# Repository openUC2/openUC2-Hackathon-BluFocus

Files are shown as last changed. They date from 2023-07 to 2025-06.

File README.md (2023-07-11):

# Hackathon: openOCT - Full-field Incoherent Interferemeter for better optical sectioning with remote control capabilities

Welcome to the openOCT Hackathon! In this hackathon, we will be addressing the crucial need for an open-source optical coherence tomography system that can help students learning more about setting up a low-coherence interferemoter. To keep the budget low, we aim for a full-field time domain OCT using an SLD (super luminescent diode) - alternatively one could also try an LED to lower the costs even more


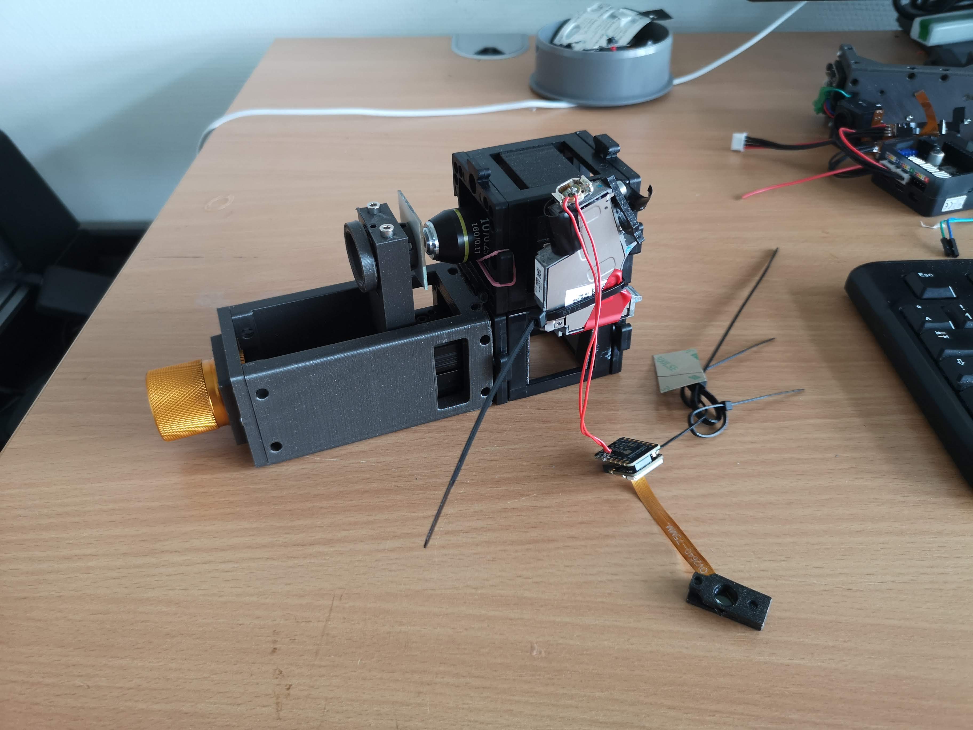
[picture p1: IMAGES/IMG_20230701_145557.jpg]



## Motivation

Autofocus is a critical feature in microscopy as it helps to keep the sample in focus, resulting in high-quality imaging. Currently, there are software-based autofocus systems that maximize contrast based on the z-position of the sample or objective. However, hardware-based autofocus systems provide alternative solutions. These systems typically utilize a laser coupled into the detection path, reflecting off the sample (e.g., coverslip), and reaching a detector (e.g., quadrant diode, camera) via a beamsplitter. As the sample moves along the optical axis, the detected beam on the detector changes as a function of *z*, which can be processed using various techniques or electric circuits.

While some major microscope manufacturers offer hardware-based autofocus systems, they tend to be expensive. Software-based systems, on the other hand, are slow and lack real-time functionality. Although neural network-based systems show promise, they are not yet stable enough. Thus, there is a clear need for an open-source hardware-based autofocus system that is affordable, precise, and accessible to anyone.

For further reading on the topic, we recommend the review article "Advances in Hardware Autofocus Systems for Microscopy" available at: [Link to Article](https://arxiv.org/pdf/2006.08610.pdf)

## Goal

The primary objective of this hackathon is to build an affordable hardware module for autofocus using readily available components, namely the optical pickup unit (OPU) from a PS3 Bluray drive and the SEEED XIAO ESP32-S3 Camera. The PS3 OPU employs an astigmatism-based autofocus technique, which maintains a constant distance between the disk and the detection lens. To replicate this functionality, we will replace the quadrant diode with a camera and utilize image processing algorithms, either on the ESP32 microcontroller or in Python, to compute the astigmatism as a function of the focus along the z-axis.

Ultimately, the goal is to create a hardware module capable of continuously tracking the focus and providing a signal to a motor, ensuring that the focus remains constant during microscopy experiments.

## Background

The use of optical pickup units (OPUs) from Bluray/HD-DVD players has been extensively explored in various applications, including force measurements, atomic force microscopy, nanoprinting, and laser scanning microscopy. These OPUs are highly integrated photonic devices with immense potential. If you're interested in delving deeper into OPU hacking, there are informative forum discussions available at: [Link to Forum](https://forum.hackteria.org/t/laser-optical-pickup-unit-hacking/771/24)

To gain a comprehensive understanding, we recommend watching this enlightening video: [Link to Video](https://www.youtube.com/watch?v=5bqujaldaCQ&ab_channel=EdwinHwu)

For a concise summary of OPU hacking, you can refer to this document: [Link to Summary](https://drive.google.com/file/d/1NFffRgITiLQYtSXz-uS6AOUKJFVFwoh7/view)

OPUs are widely available in large quantities as discarded electronic components, making them an ideal resource for hacking and repurposing.

The SEEED XIAO ESP32-S3 Camera, integrated with the ESP32 microcontroller, provides a convenient solution for streaming images over USB or Wi-Fi. Also, the microcontroller has enough power to do basic image processing such as gaussian bluring, min/max estimation, etc. Enough to evtl. do the focus computation on the device before transmitting the information to e.g. a computer.

## Current State: Building the Prototype

At present, we have a functional prototype that combines the SEEED XIAO ESP32-S3 camera (OV2640 chip) with the PS3 OPU (KES400A) for the autofocus system. During the prototyping phase, we utilize a red diode (650nm) instead of UV (405nm) or IR (850nm) to facilitate beam visibility. However, using NIR (near-infrared) diodes would be more suitable for fluorescence excitation and maintaining invisibility.

To modify the OPU, we remove the focusing lens and quadrant diode. In place of the quadrant diode, we position the camera without its lens to detect the astigmatism. This assembly is attached to a microscope objective lens, and a simple coverslip serves as a beamsplitter. The beam from the OPU to the objective lens' back focal plane (BFP) is collimated. Ideally, the camera should be confocal with the sample plane. The entire assembly takes the form of a cube, with the mirror adjustable to ensure it hits the BFP in the center and remains parallel to the optical axis.

To protect the camera (or flatband cable) from immediate damage, we use a camera with a long cable.

The simplest prototype involves replacing the diode with the camera and substituting the read-out lens with the objective lens.

### 3D printed assembly

All design files are available in the [INVENTOR](./INVENTOR) folder

All 3D printing files are available in the [STL](./STL)  folder

Setup from bottom view: 3  (ball-loaded) set screws in combination with 2 pulling springs allow the beamsplitter (18x18mm^2 coverslip) to be adjusted w.r.t. the BFP of the objective lens
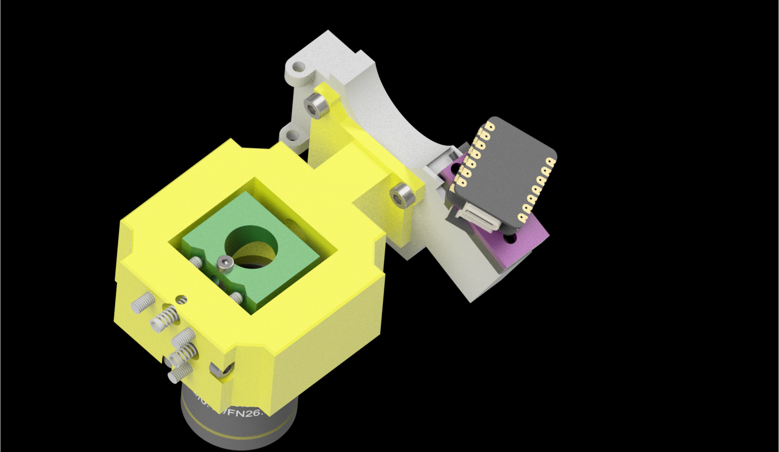
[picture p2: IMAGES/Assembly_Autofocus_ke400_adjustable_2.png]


The XIAO camera is mounted in place of the quadrant diode (A holding mechanism is missing)
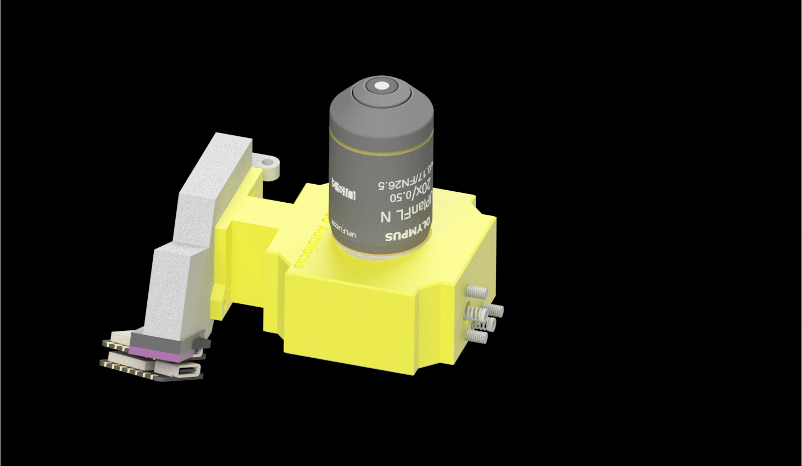
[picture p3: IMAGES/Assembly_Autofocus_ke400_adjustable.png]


The camera comes under an angle since the cylindrical lens is not perpendicular to the pixels otherwise:


### Setting up and Adapting

To disassemble the OPU, you can remove the metal plate at the back and the detection lens using Philips screwdrivers.

The back of the OPU features a complex and precisely adjusted "confocal" microscope:

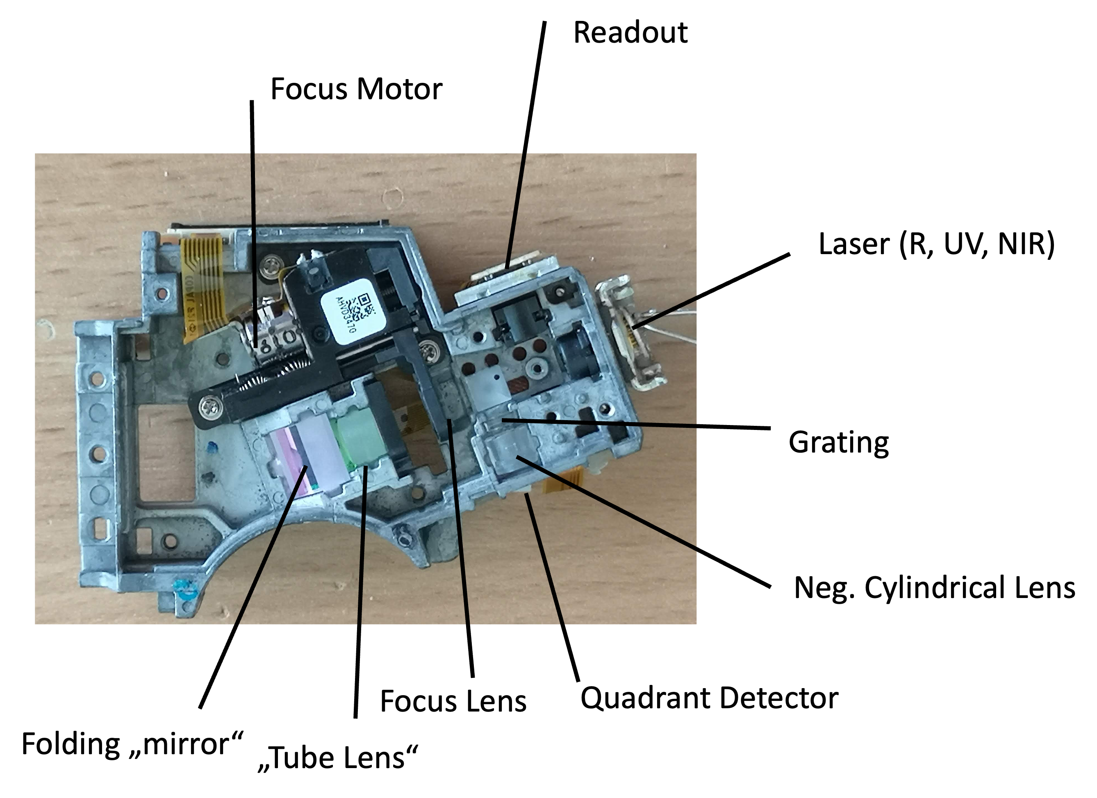
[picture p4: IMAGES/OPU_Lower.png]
OPU Lower

*Bottom View*

To attach this unit to a 3D printed assembly, we will enlarge the holes where the lens used to be, making them M3-sized, and then incorporate the assembly into a UC2 insert:

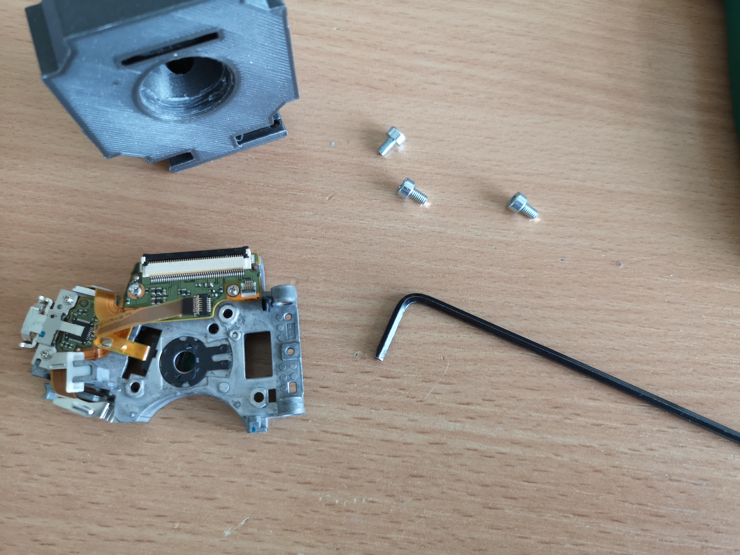
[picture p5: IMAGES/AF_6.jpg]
3D Printed Assembly


The Xiao camera module can be adapted using another 3D printed mechanism (customizable to your needs). It's worth noting that the astigmatism is not parallel to the case of the OPU, so it may be necessary to adjust the angle by rotating the camera. Additionally, the focus may be slightly closer than the plastic cap (black) of the camera module allows.

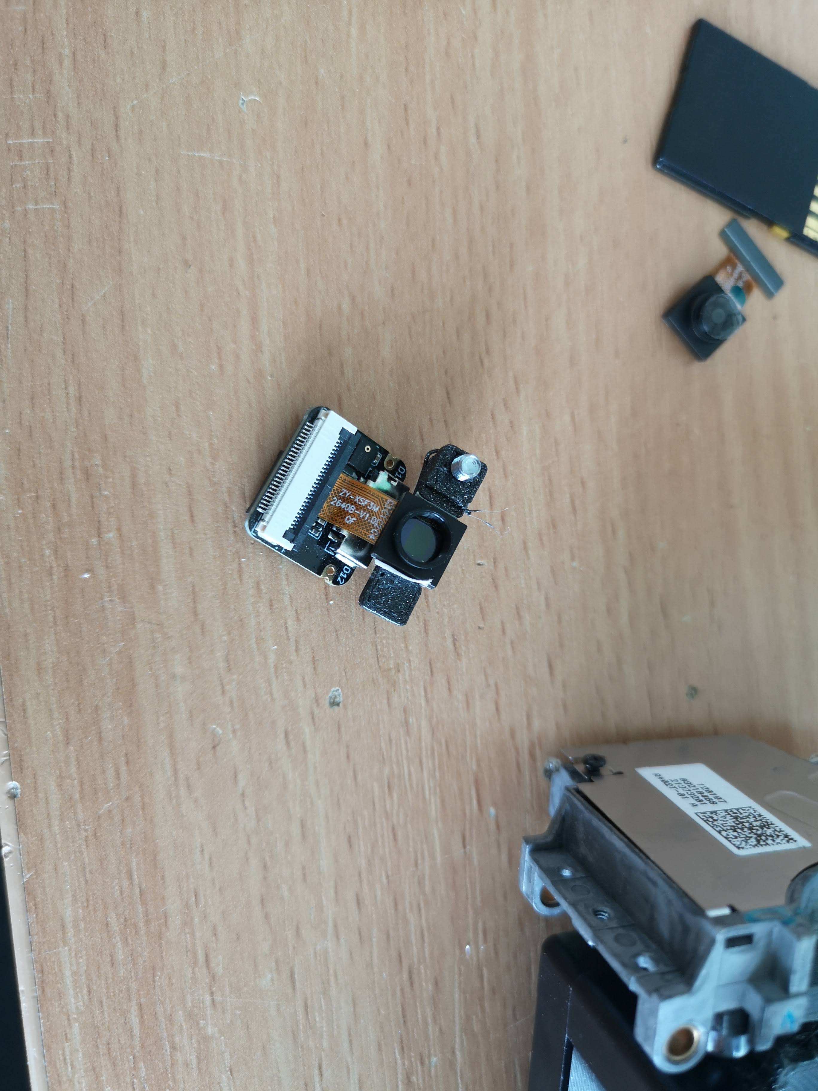
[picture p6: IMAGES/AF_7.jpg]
Xiao Camera Module


We create an initial prototype as follows:

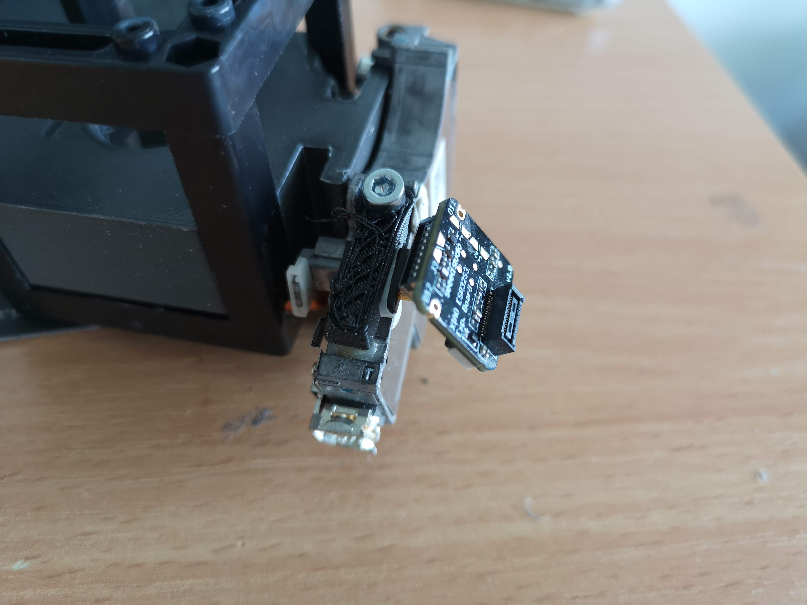
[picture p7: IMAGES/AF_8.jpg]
Prototype


It is advisable to mount the XIAO camera securely to prevent damage to the flatband cable:

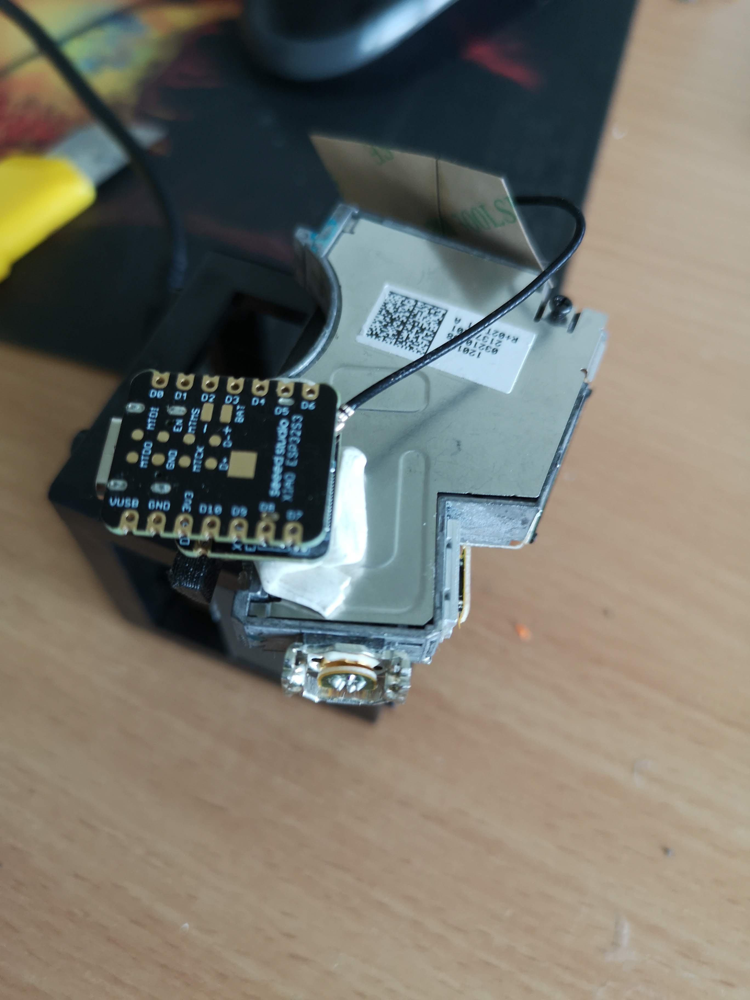
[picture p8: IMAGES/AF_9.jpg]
Secure Mounting


The laser diode can be directly powered by the 3V3 supply voltage or controlled using a transistor for on/off switching in the code.

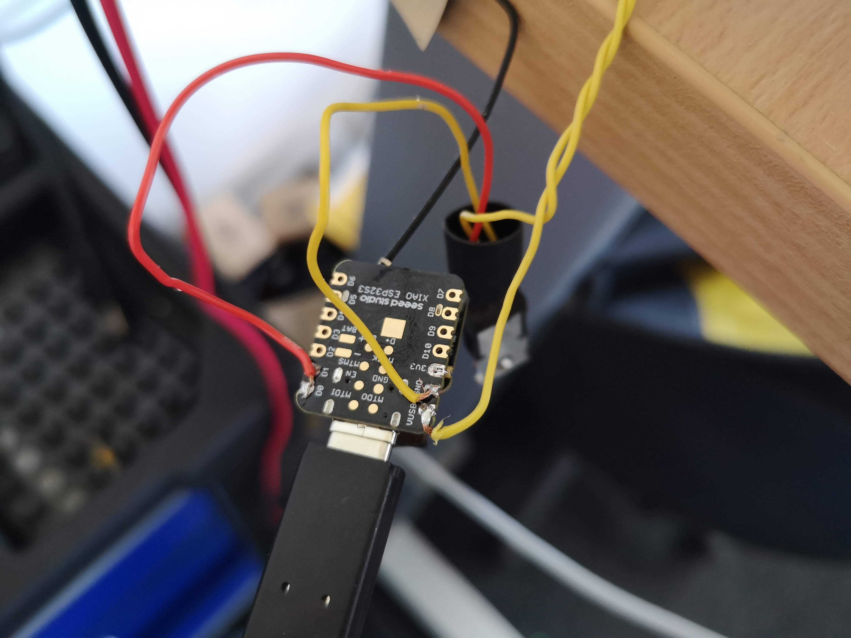
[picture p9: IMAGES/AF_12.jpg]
Laser Diode Setup


Fully assembled



### Optical Setup

The optical setup for the autofocus system involves several components and configurations. Here is an overview of the setup:

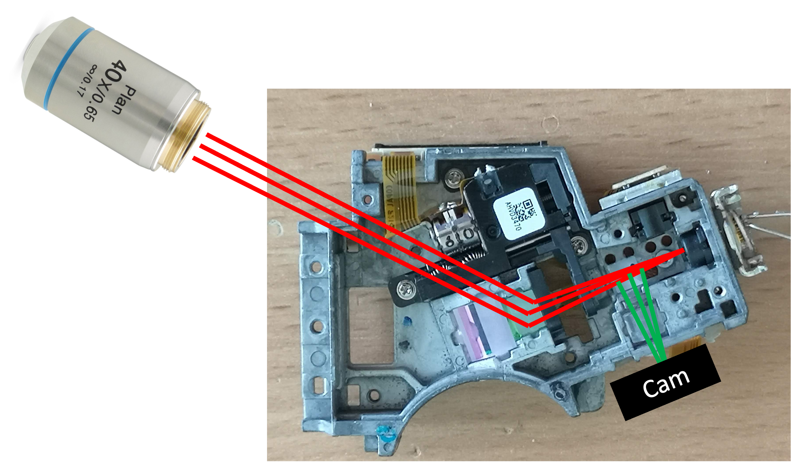
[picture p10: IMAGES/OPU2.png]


- Laser Collimation: The laser beam is roughly collimated using a lens that also features a grating. The purpose of the grating is yet to be determined.
- Spatial Light Modulator (SLM): The laser beam passes through a tiny SLM, which shapes the beam according to specific requirements.
- Polarizing Beam Splitters: The shaped beam is directed through two polarizing beam splitters before it is steered towards the objective lens.
- Polarization Rotation: The reflected light from the sample undergoes polarization rotation using a quarter-wave plate.
- Detection: The polarizing beam splitter reflects the light towards the detector. Between the beamsplitter and the detector, a small grating is positioned along with a negative cylindrical lens.
- Grating and Negative Cylindrical Lens: The combination of the grating and negative cylindrical lens plays a crucial role in the autofocus system:
  - A collimated beam results in a cross or the best-focused image on the detector.
  - An out-of-focus beam leads to a line structure along the x or y axis, depending on whether it is positively or negatively out of focus.
  - Typically, a quadrant detector is used to measure the differences between the sums of intensities (A-B)+(C-D).
  - The resulting S-curve can be used for absolute or relative focus tracking in a linear regime.
  - The S-curve switches signs at the outer regions because the astigmatism rotates as a function of atan2.

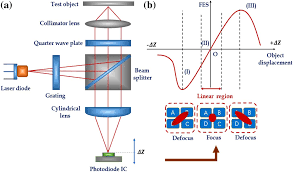
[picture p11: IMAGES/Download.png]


The practical implementation of this setup may look like the following animation:

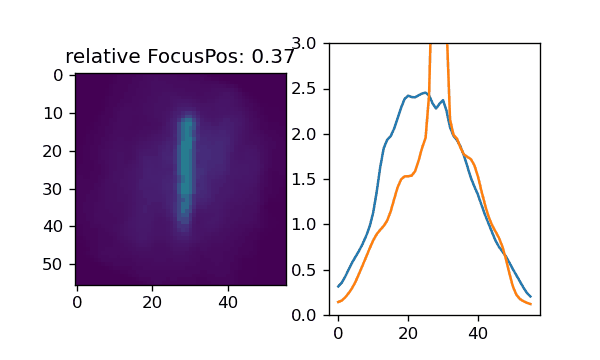
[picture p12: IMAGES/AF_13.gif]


The combination of these optical elements allows for precise detection and tracking of focus in the autofocus system.

### test Setup

Optical Setup Animation

### Code

The general code is divided into two pieces:
- cpp code that can be used in the aRduino IDE or better Platform.io in Visual studio code that reads out the camera, sets up expsoure and gain and converts the data to a byte stream to send it out via Serial
- python code to send data (E.g. request frame, setup camera parameter), receive the data and converts it to numpy arrays

The code is copied from our matchboxscope repository:
https://github.com/Matchboxscope/matchboxscope-simplecamera/tree/autofocus

#### ESP32

```cpp
#include "esp_camera.h"
#include <base64.h>

#define BAUD_RATE 2000000

#define PWDN_GPIO_NUM -1
#define RESET_GPIO_NUM -1
#define XCLK_GPIO_NUM 10
#define SIOD_GPIO_NUM 40
#define SIOC_GPIO_NUM 39

#define Y9_GPIO_NUM 48
#define Y8_GPIO_NUM 11
#define Y7_GPIO_NUM 12
#define Y6_GPIO_NUM 14
#define Y5_GPIO_NUM 16
#define Y4_GPIO_NUM 18
#define Y3_GPIO_NUM 17
#define Y2_GPIO_NUM 15
#define VSYNC_GPIO_NUM 38
#define HREF_GPIO_NUM 47
#define PCLK_GPIO_NUM 13

#define LED_GPIO_NUM 21

void grabImage();
void cameraInit();

void setup()
{
  Serial.begin(BAUD_RATE);
  Serial.setTimeout(20);
  cameraInit();
}

int Nx = 320;
int Ny = 240;
int Nroi = 50;
int x = 320 / 2;
int y = 240 / 2;
bool isStreaming = true;

/* setting expsorue time: t1000
setting gain: g1
getting frame: \n
restarting: r0 */
void loop()
{
  // Check for incoming serial commands
  if (Serial.available() > 0)
  {
    String command = Serial.readString(); // Read the command until a newline character is received
    if (command.length() > 1 && command.charAt(0) == 't')
    {
      // exposure time
      int value = command.substring(1).toInt(); // Extract the numeric part of the command and convert it to an integer
      // Use the value as needed
      // Apply manual settings for the camera
      sensor_t *s = esp_camera_sensor_get();
      s->set_gain_ctrl(s, 0);     // auto gain off (1 or 0)
      s->set_exposure_ctrl(s, 0); // auto exposure off (1 or 0)
      s->set_aec_value(s, value); // set exposure manually (0-1200)
    }
    else if (command.length() > 1 && command.charAt(0) == 'g')
    {
      // gain
      int value = command.substring(1).toInt(); // Extract the numeric part of the command and convert it to an integer

      // Apply manual settings for the camera
      sensor_t *s = esp_camera_sensor_get();
      s->set_gain_ctrl(s, 0);     // auto gain off (1 or 0)
      s->set_exposure_ctrl(s, 0); // auto exposure off (1 or 0)
      s->set_agc_gain(s, value);  // set gain manually (0 - 30)
    }
    else if (command.length() > 1 && command.charAt(0) == 'r')
    {
      // restart
      ESP.restart();
    }
    else
    {
      // capture image and return
      grabImage();
    }

    // flush serial
    while (Serial.available() > 0)
    {
      char c = Serial.read();
    }
  }
}

void cameraInit()
{

  camera_config_t config;
  config.ledc_channel = LEDC_CHANNEL_0;
  config.ledc_timer = LEDC_TIMER_0;
  config.pin_d0 = Y2_GPIO_NUM;
  config.pin_d1 = Y3_GPIO_NUM;
  config.pin_d2 = Y4_GPIO_NUM;
  config.pin_d3 = Y5_GPIO_NUM;
  config.pin_d4 = Y6_GPIO_NUM;
  config.pin_d5 = Y7_GPIO_NUM;
  config.pin_d6 = Y8_GPIO_NUM;
  config.pin_d7 = Y9_GPIO_NUM;
  config.pin_xclk = XCLK_GPIO_NUM;
  config.pin_pclk = PCLK_GPIO_NUM;
  config.pin_vsync = VSYNC_GPIO_NUM;
  config.pin_href = HREF_GPIO_NUM;
  config.pin_sscb_sda = SIOD_GPIO_NUM;
  config.pin_sscb_scl = SIOC_GPIO_NUM;
  config.pin_pwdn = PWDN_GPIO_NUM;
  config.pin_reset = RESET_GPIO_NUM;
  config.xclk_freq_hz = 20000000;
  // config.frame_size = FRAMESIZE_QVGA;
  // config.pixel_format = PIXFORMAT_JPEG; // for streaming
  // config.pixel_format = PIXFORMAT_RGB565; // for face detection/recognition
  config.grab_mode = CAMERA_GRAB_WHEN_EMPTY;
  config.fb_location = CAMERA_FB_IN_PSRAM;
  config.jpeg_quality = 12;

  config.pixel_format = PIXFORMAT_JPEG;
  config.frame_size = FRAMESIZE_QVGA; // for streaming}

  config.fb_count = 1;

  esp_err_t err = esp_camera_init(&config);
  if (err != ESP_OK)
  {
    return;
  }

  sensor_t *s = esp_camera_sensor_get();
  s->set_hmirror(s, 1);
  s->set_vflip(s, 1);

  // enable manual camera settings
  s->set_gain_ctrl(s, 0);     // auto gain off (1 or 0)
  s->set_exposure_ctrl(s, 0); // auto exposure off (1 or 0)
  s->set_aec_value(s, 100);   // set exposure manually (0-1200)
  s->set_agc_gain(s, 0);      // set gain manually (0 - 30)
}
void grabImage()
{

  camera_fb_t *fb = esp_camera_fb_get();

  if (!fb || fb->format != PIXFORMAT_JPEG)
  {
    Serial.println("Failed to capture image");
    ESP32.restart();
  }
  else
  {
    delay(40);

    String encoded = base64::encode(fb->buf, fb->len);
    Serial.write(encoded.c_str(), encoded.length());
    Serial.println();
  }

  esp_camera_fb_return(fb);
}
```

#### PYTHON

```py
import time
from threading import Thread
import numpy as np
import serial.tools.list_ports
import base64
from PIL import Image
import io

class CameraESP32CamSerial:
    def __init__(self):
        super().__init__()
        self.__logger = initLogger(self, tryInheritParent=True)

        # many to be purged
        self.model = "ESP32Camera"
        self.shape = (0, 0)

        self.isConnected = False

        # camera parameters
        self.framesize = 100
        self.exposure_time = 0
        self.analog_gain = 0

        self.SensorWidth = 320
        self.SensorHeight = 240

        self.manufacturer = 'Espressif'

        self.frame = np.ones((self.SensorHeight,self.SensorWidth))
        self.isRunning = False

        # string to send data to camera
        self.newCommand = ""
        self.exposureTime = -1
        self.gain = -1

        self.serialdevice = self.connect_to_usb_device()

    def connect_to_usb_device(self):
        ports = serial.tools.list_ports.comports()
        for port in ports:
            if port.manufacturer == self.manufacturer or port.manufacturer=="Microsoft":
                try:
                    ser = serial.Serial(port.device, baudrate=2000000, timeout=1)
                    print(f"Connected to device: {port.description}")
                    return ser
                except serial.SerialException:
                    print(f"Failed to connect to device: {port.description}")
        print("No matching USB device found.")
        return None

    def put_frame(self, frame):
        self.frame = frame
        return frame

    def start_live(self):
        self.isRunning = True
        self.mThread = Thread(target=self.startStreamingThread)
        self.mThread.start()

    def stop_live(self):
        self.isRunning = False
        self.mThread.join()
        try:self.serialdevice.close()
        except:pass

    def suspend_live(self):
        self.isRunning = False

    def prepare_live(self):
        pass

    def close(self):
        try:self.serialdevice.close()
        except:pass

    def setPropertyValue(self, property_name, property_value):
        # Check if the property exists.
        if property_name == "gain":
            self.set_analog_gain(property_value)
        elif property_name == "exposure":
            self.set_exposure_time(property_value)
        else:
            self.__logger.warning(f'Property {property_name} does not exist')
            return False
        return property_value

    def getPropertyValue(self, property_name):
        # Check if the property exists.
        if property_name == "gain":
            property_value = self.gain
        elif property_name == "exposure":
            property_value = self.exposureTime
        else:
            self.__logger.warning(f'Property {property_name} does not exist')
            return False
        return property_value

    def set_exposure_time(self, exposureTime):
        self.newCommand = "t"+str(exposureTime)
        self.exposureTime = exposureTime

    def set_analog_gain(self, gain):
        self.newCommand = "g"+str(gain)
        self.gain = gain

    def getLast(self):
        return self.frame

    def startStreamingThread(self):
        # if we have never connected anything we should return and not always try to reconnecnt
        if self.serialdevice is None:
            return
        nFrame = 0
        nTrial = 0
        while self.isRunning:
            try:

                # send new comamand to change camera settings, reset command    
                if not self.newCommand == "":
                    self.serialdevice.write((self.newCommand+' \n').encode())
                    self.newCommand = ""

                # request new image
                self.serialdevice.write((' \n').encode())

                # don't read to early
                time.sleep(.05)
                # readline of camera
                imageB64 = self.serialdevice.readline()

                # decode byte stream
                image = np.array(Image.open(io.BytesIO(base64.b64decode(imageB64.decode()))))
                self.frame = np.mean(image,-1)

                nFrame += 1

            except Exception as e:
                # try to reconnect
                #print(e) # most of the time "incorrect padding of the bytes "
                nFrame = 0
                nTrial+=1
                try:
                    self.serialdevice.flushInput()
                    self.serialdevice.flushOutput()
                except:
                    pass
                if nTrial > 10 and type(e)==serial.serialutil.SerialException:
                    try:
                        # close the device - similar to hard reset
                        self.serialdevice.setDTR(False)
                        self.serialdevice.setRTS(True)
                        time.sleep(.1)
                        self.serialdevice.setDTR(False)
                        self.serialdevice.setRTS(False)
                        time.sleep(.5)
                        #self.serialdevice.close()
                    except: pass
                    self.serialdevice = self.connect_to_usb_device()
                    nTrial = 0

    def getLastChunk(self):
        return self.frame

    def setROI(self, hpos, vpos, hsize, vsize):
        return #hsize = max(hsize, 256)  # minimum ROI

```

#### Image Processing

More scripts can be found here:
https://github.com/Matchboxscope/matchboxscope-simplecamera/tree/autofocus/PYTHON

A test stack for the astimatism can be found here:
https://github.com/Matchboxscope/matchboxscope-simplecamera/raw/autofocus/PYTHON/realAstigmatismStack.tif

#### ImSwitch

We want to be able to use this as an online-running autofocus in ImSwitch. Relevant code passages are the camera interface for the herein created USB-serial camera:

https://github.com/openUC2/ImSwitch/blob/d3009b2dd669fbee273cca770c87c8c80d0c5940/imswitch/imcontrol/model/interfaces/CameraESP32CamSerial.py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

The FocusLockController

https://github.com/openUC2/ImSwitch/blob/d3009b2dd669fbee273cca770c87c8c80d0c5940/imswitch/imcontrol/controller/controllers/FocusLockController.py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

### How to set up?

## Safety

## Challenge

### Varitions

## When Goal is met?

- have one working system
- Detect the focus as one number from the astimatism as a function of the z-position
- have a controller that may give step-values for the focus motor
- have a functioning focuscontroller inside imswitch that can keep the focus

## Ressources
- https://hackaday.com/2021/02/02/dvd-optics-power-this-scanning-laser-microscope/

## License

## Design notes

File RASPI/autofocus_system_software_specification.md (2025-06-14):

# Autofocus System Software Specification (Raspberry Pi Zero W2)

example code can be found in the folder /RASPI

## 1 Scope
Design and implement lightweight software that acquires camera frames, evaluates focus quality for each frame, streams video for debugging, exposes runtime configuration via REST, and publishes per‑frame focus metrics over CAN bus. Runs headless on Raspberry Pi Zero W2 and ships as a bootable OS image.

## 2 Target Hardware
| Component | Details |
|---|---|
| SBC | Raspberry Pi Zero W2, 1 GHz quad‑core, 512 MB RAM |
| Camera | CSI‑2 camera (e.g. HQ camera); sensor supports manual exposure & gain |
| CAN | Waveshare RS485_CAN_HAT connected to Pi GPIO / SPI |
| Network | 2.4 GHz Wi‑Fi (credentials pre‑set via **boot.txt**) |

## 3 Operating System & Base Image
* Raspberry Pi OS Lite 64‑bit (Debian 12)
* Custom image built with `pi-gen`; Wi‑Fi SSID/PSK injected into `/boot/wpa_supplicant.conf`.
* Enable UART, I2C, SPI, and camera in `/boot/config.txt`.

## 4 Processes & Services
### 4.1 `focusd` – main service (Python ≥3.11)
* Captures frames from the CSI camera at ≤ 15 fps using `libcamera`.
* Applies user‑defined exposure & gain on each capture.
* Calls **FocusMetric.compute(frame)** (algorithm described in §5) and obtains a single `float` per frame.
* Publishes metric to CAN (event‑push every frame *and* on‑demand pull, §6).
* Exposes MJPEG stream of raw frames on `http://<pi>:8080/stream.mjpg` for live debug.
* Exposes REST API via FastAPI (see §7).
* Persists settings in `/etc/focusd/config.yaml`; loads on startup.
* Implemented as `systemd` service; auto‑restart.

### 4.2 `focusd_api` (FastAPI under Uvicorn)
Runs inside same process or separate; provides REST + WebSocket.

### 4.3 `can0` bring‑up script
```bash
ip link set can0 type can bitrate 100000
ifconfig can0 up
```
Add to `/etc/rc.local` or dedicated `systemd` service.

## 5 Focus Metric Algorithm
1. Convert frame to grayscale (`numpy uint8`).
2. (Optional) Gaussian blur σ ≈ 11 px to suppress noise.
3. Threshold: `im[im < background] = 0`, `background` configurable.
4. Compute mean projections `projX`, `projY`.
5. Fit `projX` with double‑Gaussian, `projY` with single‑Gaussian (SciPy `curve_fit`).
6. Focus value `F = σx / σy` (float32).
7. Return timestamped JSON `{ "t": 1686844861.012, "focus": F }`.

Provide `focus_algorithm.py` with clear API so algorithm can later be hot‑swapped or ported to C++.

## 6 CAN Bus Interface
* `socketcan` driver.
* Arbitration ID: `0x123` (configurable).
* Data payload: first 4 bytes little‑endian IEEE‑754 float = focus value; remaining bytes reserved.
* Push mode: transmit every processed frame.
* Pull mode: on receiving CAN message with ID `0x124`, immediately send latest value.
* Use `python‑can`; abstraction layer so C++ can reuse message format.

## 7 REST API (FastAPI)

This is mostly for debugging; useses Swagger

| Method & path | Purpose |
|---|---|
| `GET /status` | health, version, uptime |
| `GET /config` | return current config YAML |
| `POST /config` | update config; body = partial YAML |
| `POST /capture` | grab single frame, return JPEG |
| `GET /focus` | latest focus value JSON |
| `GET /stream` | stream mjpeg data |

All writes trigger persistent save to `/etc/focusd/config.yaml`.

## 8 Performance Targets
* CPU ≤ 70 % of single core at 10 fps.
* RAM ≤ 120 MB resident.
* Boot‑to‑ready ≤ 25 s.
* CAN latency (frame → publish) ≤ 40 ms.

## 9 Logging & Monitoring
* `systemd‑journald` for service stdout/err.
* Optional MQTT publishing of metrics for remote dashboards.
* Rotate MJPEG stream to RAM‑disk to avoid SD wear.

## 10 Deployment & Deliverables
1. **Git repo** with structured modules:
   * `focusd/` core service
   * `api/` FastAPI app
   * `algorithms/` focus metrics
   * `scripts/` bring‑up, build‑image
2. **Dockerfile** for CI lint/unit‑tests (runs on x86 CI server).
3. **Pi image build script** (`build_image.sh`) producing `focusd-<date>.img`.
4. **README.md**: flashing instructions, API examples, CAN trace examples.
5. **Unit tests** (pytest) incl. synthetic frame fixtures.
6. **Benchmark report** against performance targets.
7. Optional: C++ port stub using `pybind11`.

## 11 Timeline (example)
| Week | Milestone |
|---|---|
| 1 | repo skeleton, CAN setup validated |
| 2 | camera capture + MJPEG + REST skeleton |
| 3 | algorithm integrated, unit tests passing |
| 4 | CAN push/pull implemented, performance tuned |
| 5 | image build pipeline, documentation, hand‑off |

## 12 Acceptance Criteria
* Flash image, power‑up Pi, connect to predefined Wi‑Fi, open `http://<pi>:8080/stream.mjpg` and see live video.
* `curl -X POST /config -d '{"exposure":1500}'` updates sensor and value persists after reboot.
* External CAN bus receives focus value for every frame within 40 ms.
* System meets performance & resource constraints.

---
End of specification.

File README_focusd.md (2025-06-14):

# focusd - Autofocus System for Raspberry Pi Zero W2

A lightweight autofocus system that acquires camera frames, evaluates focus quality, streams video for debugging, exposes runtime configuration via REST API, and publishes per-frame focus metrics over CAN bus.

## 🎯 Features

- **Real-time focus computation** using double/single Gaussian fitting algorithm
- **Camera capture** at ≤15 fps using libcamera (with fallbacks)
- **MJPEG video streaming** for live debugging on port 8080
- **REST API** for configuration and control
- **CAN bus interface** for real-time focus metrics (push/pull modes)
- **Configuration persistence** with YAML files
- **SystemD integration** for auto-start and monitoring
- **Performance optimized** for Raspberry Pi Zero W2

## 📋 Requirements

### Hardware
- Raspberry Pi Zero W2 (1 GHz quad-core, 512 MB RAM)
- CSI-2 camera (e.g., HQ camera with manual exposure & gain)
- Waveshare RS485_CAN_HAT connected to Pi GPIO/SPI
- 2.4 GHz Wi-Fi connectivity

### Software
- Raspberry Pi OS Lite 64-bit (Debian 12)
- Python ≥3.11
- See `requirements.txt` for Python dependencies

## 🚀 Quick Start

### 1. Flash and Boot

Flash the provided `focusd-YYYYMMDD.img` to an SD card:

```bash
# Flash image (replace with actual image filename)
sudo dd if=focusd-20241214.img of=/dev/sdX bs=4M status=progress

# Or use Raspberry Pi Imager with the .img file
```

### 2. Initial Setup

1. Insert SD card and boot Pi
2. Connect to predefined Wi-Fi network
3. Find Pi IP address (check router or use `nmap`)
4. Access live video stream: `http://<pi-ip>:8080/stream`

### 3. API Usage Examples

#### Check System Status
```bash
curl http://<pi-ip>:8080/status
```

#### Get Current Configuration
```bash
curl http://<pi-ip>:8080/config
```

#### Update Camera Settings
```bash
curl -X POST http://<pi-ip>:8080/config \
  -H "Content-Type: application/json" \
  -d '{"camera": {"exposure": 1500, "gain": 10}}'
```

#### Capture Single Frame
```bash
curl http://<pi-ip>:8080/capture > capture.jpg
```

#### Get Latest Focus Value
```bash
curl http://<pi-ip>:8080/focus
# Returns: {"t": 1686844861.012, "focus": 1.234}
```

### 4. CAN Bus Monitoring

Monitor focus values on CAN bus:

```bash
# On Pi or connected device with can-utils
candump can0

# Example output:
# can0  123   [8]  3F 9D B2 2D 00 00 00 00  # Focus value as IEEE-754 float
```

Send focus request (pull mode):
```bash
cansend can0 124#
# Pi will immediately respond with latest focus value on ID 0x123
```

## 🏗️ Installation from Source

### On Raspberry Pi

```bash
# Clone repository
git clone https://github.com/openUC2/openUC2-Hackathon-BluFocus.git
cd openUC2-Hackathon-BluFocus

# Install system dependencies
sudo apt update
sudo apt install -y python3 python3-pip can-utils libopencv-dev

# Install Python dependencies
pip3 install -r requirements.txt

# Install focusd
sudo pip3 install -e .

# Setup CAN interface
sudo ./scripts/setup-can.sh

# Install systemd services
sudo cp scripts/focusd.service /etc/systemd/system/
sudo cp scripts/can0-setup.service /etc/systemd/system/
sudo systemctl daemon-reload
sudo systemctl enable focusd can0-setup

# Start services
sudo systemctl start can0-setup
sudo systemctl start focusd

# Check status
sudo systemctl status focusd
```

### For Development

```bash
# Clone and setup development environment
git clone https://github.com/openUC2/openUC2-Hackathon-BluFocus.git
cd openUC2-Hackathon-BluFocus

# Install with development dependencies
pip3 install -e ".[dev]"

# Run tests
pytest tests/ -v

# Run linting
flake8 .
black .

# Run in development mode
python3 -m focusd.main --config config.yaml --log-level DEBUG
```

## 📖 API Reference

### Endpoints

| Method | Path | Description |
|---|---|---|
| `GET` | `/` | Root endpoint with service info |
| `GET` | `/status` | System health, version, uptime |
| `GET` | `/config` | Current configuration (YAML) |
| `POST` | `/config` | Update configuration |
| `POST` | `/capture` | Capture single frame (JPEG) |
| `GET` | `/focus` | Latest focus value (JSON) |
| `GET` | `/stream` | MJPEG video stream |
| `GET` | `/docs` | Swagger documentation |

### Configuration Structure

```yaml
camera:
  fps: 10
  exposure: 1000  # microseconds
  gain: 0         # 0-30
  width: 320
  height: 240

focus_algorithm:
  gaussian_sigma: 11.0
  background_threshold: 40
  crop_radius: 300
  enable_gaussian_blur: true

can:
  interface: "can0"
  bitrate: 100000
  arbitration_id_tx: 0x123
  arbitration_id_rx: 0x124
  enable_push_mode: true
  enable_pull_mode: true

api:
  host: "0.0.0.0"
  port: 8080
  enable_docs: true
  cors_enabled: true

system:
  log_level: "INFO"
  config_file: "/etc/focusd/config.yaml"
  pid_file: "/var/run/focusd.pid"
```

## 🧪 Testing

### Unit Tests

```bash
# Run all tests
pytest tests/ -v

# Run specific test categories
pytest tests/test_focus_algorithm.py -v
pytest tests/test_focusd.py::TestConfigManager -v

# Run with coverage
pytest tests/ --cov=focusd --cov=algorithms --cov=api
```

### Manual Testing

```bash
# Test focus algorithm with synthetic data
python3 tests/test_focus_algorithm.py

# Test camera interface (dummy mode)
python3 -c "
from focusd.camera import CameraInterface
camera = CameraInterface()
camera.start()
import time; time.sleep(2)
frame = camera.get_latest_frame()
print(f'Frame shape: {frame.shape if frame is not None else None}')
camera.stop()
"

# Test API endpoints
python3 -m focusd.main &
sleep 5
curl http://localhost:8080/status
curl http://localhost:8080/focus
pkill -f focusd.main
```

## 🔧 Troubleshooting

### Common Issues

**Camera not working:**
```bash
# Check libcamera installation
libcamera-still --version

# Check camera detection
libcamera-hello --list-cameras

# Enable camera in config
sudo raspi-config  # Enable camera interface
```

**CAN interface issues:**
```bash
# Check CAN hardware
dmesg | grep -i can

# Manual CAN setup
sudo ip link set can0 down
sudo ip link set can0 type can bitrate 100000
sudo ip link set can0 up

# Test CAN
cansend can0 123#DEADBEEF
candump can0
```

**Service not starting:**
```bash
# Check service status
sudo systemctl status focusd

# Check logs
sudo journalctl -u focusd -f

# Manual start for debugging
sudo -u focusd python3 -m focusd.main --log-level DEBUG
```

**Performance issues:**
```bash
# Monitor CPU usage
top -p $(pgrep -f focusd)

# Check memory usage
cat /proc/$(pgrep -f focusd)/status | grep VmRSS

# Monitor frame processing
sudo journalctl -u focusd -f | grep "Performance"
```

### Performance Targets

| Metric | Target | How to Check |
|---|---|---|
| CPU Usage | ≤70% of single core | `top`, check focusd process |
| RAM Usage | ≤120 MB resident | Check VmRSS in `/proc/PID/status` |
| Boot time | ≤25s to ready | `systemd-analyze critical-chain` |
| CAN latency | ≤40ms frame→publish | Check logs for timing warnings |

## 🔌 CAN Message Format

### Focus Value Publication (ID 0x123)
```
Bytes 0-3: Focus value (IEEE-754 float, little-endian)
Bytes 4-7: Reserved (0x00)
```

### Focus Request (ID 0x124)
```
Data: Empty (triggers immediate focus value response)
```

### Example CAN Traces

```bash
# Focus value 1.234 published
can0  123   [8]  3F 9D B2 2D 00 00 00 00

# Focus request
can0  124   [0]

# Immediate response with current value
can0  123   [8]  40 12 34 56 00 00 00 00
```

## 📊 Performance Monitoring

### Built-in Metrics

The service logs performance statistics every 30 seconds:

```bash
# View performance logs
sudo journalctl -u focusd -f | grep Performance

# Example output:
# Performance: 9.8 fps, 294 frames processed in 30.0s
```

### External Monitoring

```bash
# Monitor via API
curl http://<pi-ip>:8080/status

# Monitor CAN traffic
candump can0 -t a | grep 123

# System resources
htop
iotop
```

## 🔄 Building Custom Images

```bash
# Build Pi image with focusd
./scripts/build_image.sh

# This creates:
# - Pi-gen configuration for custom image
# - focusd distribution archive
# - Installation instructions
```

## 📜 License

This project is licensed under the MIT License - see the LICENSE file for details.

## 🤝 Contributing

1. Fork the repository
2. Create feature branch (`git checkout -b feature/amazing-feature`)
3. Run tests (`pytest tests/ -v`)
4. Commit changes (`git commit -m 'Add amazing feature'`)
5. Push branch (`git push origin feature/amazing-feature`)
6. Open Pull Request

## 📞 Support

- **Issues**: https://github.com/openUC2/openUC2-Hackathon-BluFocus/issues
- **Discussions**: https://github.com/openUC2/openUC2-Hackathon-BluFocus/discussions
- **Wiki**: https://github.com/openUC2/openUC2-Hackathon-BluFocus/wiki

## 🏆 Acknowledgments

- openUC2 project for the hardware platform
- Original autofocus algorithm research
- Raspberry Pi Foundation for the platform
- Contributors and testers

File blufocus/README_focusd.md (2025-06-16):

# focusd - Autofocus System for Raspberry Pi Zero W2

A lightweight autofocus system that acquires camera frames, evaluates focus quality, streams video for debugging, exposes runtime configuration via REST API, and publishes per-frame focus metrics over CAN bus.

## Features

- **Real-time focus computation** using double/single Gaussian fitting algorithm
- **Camera capture** at ≤15 fps using libcamera (with fallbacks)
- **MJPEG video streaming** over HTTPS for live debugging (avoids mixed content issues)
- **REST API** for configuration and control (served over HTTPS by default)
- **CAN bus interface** for real-time focus metrics (push/pull modes)
- **Configuration persistence** with YAML files
- **SystemD integration** for auto-start and monitoring
- **Performance optimized** for Raspberry Pi Zero W2
- **Automatic SSL certificate generation** for secure communication

## Requirements

### Hardware
- Raspberry Pi Zero W2 (1 GHz quad-core, 512 MB RAM)
- CSI-2 camera (e.g., HQ camera with manual exposure & gain)
- Waveshare RS485_CAN_HAT connected to Pi GPIO/SPI
- 2.4 GHz Wi-Fi connectivity

### Software
- Raspberry Pi OS Lite 64-bit (Debian 12)
- Python ≥3.11
- See `requirements.txt` for Python dependencies

## Quick Start

### 1. Flash and Boot

Flash the provided `focusd-YYYYMMDD.img` to an SD card:

```bash
#  use Raspberry Pi Imager with the .img file
```

### 2. Initial Setup

1. Insert SD card and boot Pi
2. Connect to predefined Wi-Fi network
3. Find Pi IP address (check router or use `nmap`)
4. Access live video stream: `https://<pi-ip>:8080/stream` (HTTPS enabled by default)
   - **Note**: You may need to accept the self-signed certificate warning in your browser

### 3. API Usage Examples

#### Swagger 

Visit https://<pi-ip>:8080/docs (served over HTTPS by default)

#### Check System Status
```bash
curl -k https://<pi-ip>:8080/status
```

#### Get Current Configuration
```bash
curl -k https://<pi-ip>:8080/config
```

#### Update Camera Settings
```bash
curl -k -X POST https://<pi-ip>:8080/config \
  -H "Content-Type: application/json" \
  -d '{"camera": {"exposure": 1500, "gain": 10}}'
```

#### Capture Single Frame
```bash
curl -k https://<pi-ip>:8080/capture > capture.jpg
```

#### Get Latest Focus Value
```bash
curl -k https://<pi-ip>:8080/focus
# Returns: {"t": 1686844861.012, "focus": 1.234}
```

**Note**: The `-k` flag tells curl to ignore SSL certificate errors (needed for self-signed certificates)

### 4. CAN Bus Monitoring

Monitor focus values on CAN bus:

```bash
# On Pi or connected device with can-utils
candump can0

# Example output:
# can0  123   [8]  3F 9D B2 2D 00 00 00 00  # Focus value as IEEE-754 float
```

Send focus request (pull mode):
```bash
cansend can0 124#
# Pi will immediately respond with latest focus value on ID 0x123
```

## 🏗️ Installation from Source

### On Raspberry Pi

```bash
# Clone repository
git clone https://github.com/openUC2/openUC2-Hackathon-BluFocus.git
cd openUC2-Hackathon-BluFocus/blufocus

# Install system dependencies
sudo apt update
sudo apt install -y python3 python3-pip can-utils libopencv-dev

# Install Python dependencies
pip3 install -r requirements.txt

# Install focusd
sudo pip3 install -e .

# Setup CAN interface
sudo ./scripts/setup-can.sh

# Install systemd services
sudo cp scripts/focusd.service /etc/systemd/system/
sudo cp scripts/can0-setup.service /etc/systemd/system/
sudo systemctl daemon-reload
sudo systemctl enable focusd can0-setup

# Start services
sudo systemctl start can0-setup
sudo systemctl start focusd

# Check status
sudo systemctl status focusd
```

### For Development

```bash
# Clone and setup development environment
git clone https://github.com/openUC2/openUC2-Hackathon-BluFocus.git
cd openUC2-Hackathon-BluFocus

# Install with development dependencies
pip3 install -e ".[dev]"

# Run tests
pytest tests/ -v

# Run linting
flake8 .
black .

# Run in development mode
python3 -m focusd.main --config config.yaml --log-level DEBUG
```

## API Reference

### Endpoints

| Method | Path | Description |
|---|---|---|
| `GET` | `/` | Root endpoint with service info |
| `GET` | `/status` | System health, version, uptime |
| `GET` | `/config` | Current configuration (YAML) |
| `POST` | `/config` | Update configuration |
| `POST` | `/capture` | Capture single frame (JPEG) |
| `GET` | `/focus` | Latest focus value (JSON) |
| `GET` | `/stream` | MJPEG video stream |
| `GET` | `/docs` | Swagger documentation |

### Configuration Structure

```yaml
camera:
  fps: 10
  exposure: 1000  # microseconds
  gain: 0         # 0-30
  width: 320
  height: 240

focus_algorithm:
  gaussian_sigma: 11.0
  background_threshold: 40
  crop_radius: 300
  enable_gaussian_blur: true

can:
  interface: "can0"
  bitrate: 100000
  arbitration_id_tx: 0x123
  arbitration_id_rx: 0x124
  enable_push_mode: true
  enable_pull_mode: true

api:
  host: "0.0.0.0"
  port: 8080
  enable_docs: true
  cors_enabled: true
  enable_ssl: true  # HTTPS enabled by default
  ssl_cert_path: "/etc/focusd/ssl/cert.pem"
  ssl_key_path: "/etc/focusd/ssl/key.pem"

system:
  log_level: "INFO"
  config_file: "/etc/focusd/config.yaml"
  pid_file: "/var/run/focusd.pid"
```

### HTTPS Configuration

HTTPS is enabled by default to prevent mixed content issues when accessing the video stream from HTTPS web pages. The system automatically generates self-signed certificates if they don't exist.

#### Disabling HTTPS (not recommended)
```yaml
api:
  enable_ssl: false
```

#### Custom SSL Certificates
Replace the auto-generated certificates with your own:
```bash
sudo cp your-cert.pem /etc/focusd/ssl/cert.pem
sudo cp your-key.pem /etc/focusd/ssl/key.pem
sudo systemctl restart focusd
```

## Testing

### Unit Tests

```bash
# Run all tests
pytest tests/ -v

# Run specific test categories
pytest tests/test_focus_algorithm.py -v
pytest tests/test_focusd.py::TestConfigManager -v

# Run with coverage
pytest tests/ --cov=focusd --cov=algorithms --cov=api
```

### Manual Testing

```bash
# Test focus algorithm with synthetic data
python3 tests/test_focus_algorithm.py

# Test camera interface (dummy mode)
python3 -c "
from focusd.camera import CameraInterface
camera = CameraInterface()
camera.start()
import time; time.sleep(2)
frame = camera.get_latest_frame()
print(f'Frame shape: {frame.shape if frame is not None else None}')
camera.stop()
"

# Test API endpoints
python3 -m focusd.main &
sleep 5
curl -k https://localhost:8080/status
curl -k https://localhost:8080/focus
pkill -f focusd.main
```

## Troubleshooting

### Common Issues

**Camera not working:**
```bash
# Check libcamera installation
libcamera-still --version

# Check camera detection
libcamera-hello --list-cameras

# Enable camera in config
sudo raspi-config  # Enable camera interface
```

**CAN interface issues:**
```bash
# Check CAN hardware
dmesg | grep -i can

# Manual CAN setup
sudo ip link set can0 down
sudo ip link set can0 type can bitrate 100000
sudo ip link set can0 up

# Test CAN
cansend can0 123#DEADBEEF
candump can0
```

**Service not starting:**
```bash
# Check service status
sudo systemctl status focusd

# Check logs
sudo journalctl -u focusd -f

# Manual start for debugging
sudo -u focusd python3 -m focusd.main --log-level DEBUG
```

**Performance issues:**
```bash
# Monitor CPU usage
top -p $(pgrep -f focusd)

# Check memory usage
cat /proc/$(pgrep -f focusd)/status | grep VmRSS

# Monitor frame processing
sudo journalctl -u focusd -f | grep "Performance"
```

### Performance Targets

| Metric | Target | How to Check |
|---|---|---|
| CPU Usage | ≤70% of single core | `top`, check focusd process |
| RAM Usage | ≤120 MB resident | Check VmRSS in `/proc/PID/status` |
| Boot time | ≤25s to ready | `systemd-analyze critical-chain` |
| CAN latency | ≤40ms frame→publish | Check logs for timing warnings |

## 🔌 CAN Message Format

### Focus Value Publication (ID 0x123)
```
Bytes 0-3: Focus value (IEEE-754 float, little-endian)
Bytes 4-7: Reserved (0x00)
```

### Focus Request (ID 0x124)
```
Data: Empty (triggers immediate focus value response)
```

### Example CAN Traces

```bash
# Focus value 1.234 published
can0  123   [8]  3F 9D B2 2D 00 00 00 00

# Focus request
can0  124   [0]

# Immediate response with current value
can0  123   [8]  40 12 34 56 00 00 00 00
```

## 📊 Performance Monitoring

### Built-in Metrics

The service logs performance statistics every 30 seconds:

```bash
# View performance logs
sudo journalctl -u focusd -f | grep Performance

# Example output:
# Performance: 9.8 fps, 294 frames processed in 30.0s
```

### External Monitoring

```bash
# Monitor via API
curl http://<pi-ip>:8080/status

# Monitor CAN traffic
candump can0 -t a | grep 123

# System resources
htop
iotop
```

## 🔄 Building Custom Images

```bash
# Build Pi image with focusd
./scripts/build_image.sh

# This creates:
# - Pi-gen configuration for custom image
# - focusd distribution archive
# - Installation instructions
```

## 📜 License

This project is licensed under the MIT License - see the LICENSE file for details.

## 🤝 Contributing

1. Fork the repository
2. Create feature branch (`git checkout -b feature/amazing-feature`)
3. Run tests (`pytest tests/ -v`)
4. Commit changes (`git commit -m 'Add amazing feature'`)
5. Push branch (`git push origin feature/amazing-feature`)
6. Open Pull Request

## 📞 Support

- **Issues**: https://github.com/openUC2/openUC2-Hackathon-BluFocus/issues
- **Discussions**: https://github.com/openUC2/openUC2-Hackathon-BluFocus/discussions
- **Wiki**: https://github.com/openUC2/openUC2-Hackathon-BluFocus/wiki

## 🏆 Acknowledgments

- openUC2 project for the hardware platform
- Original autofocus algorithm research
- Raspberry Pi Foundation for the platform
- Contributors and testers

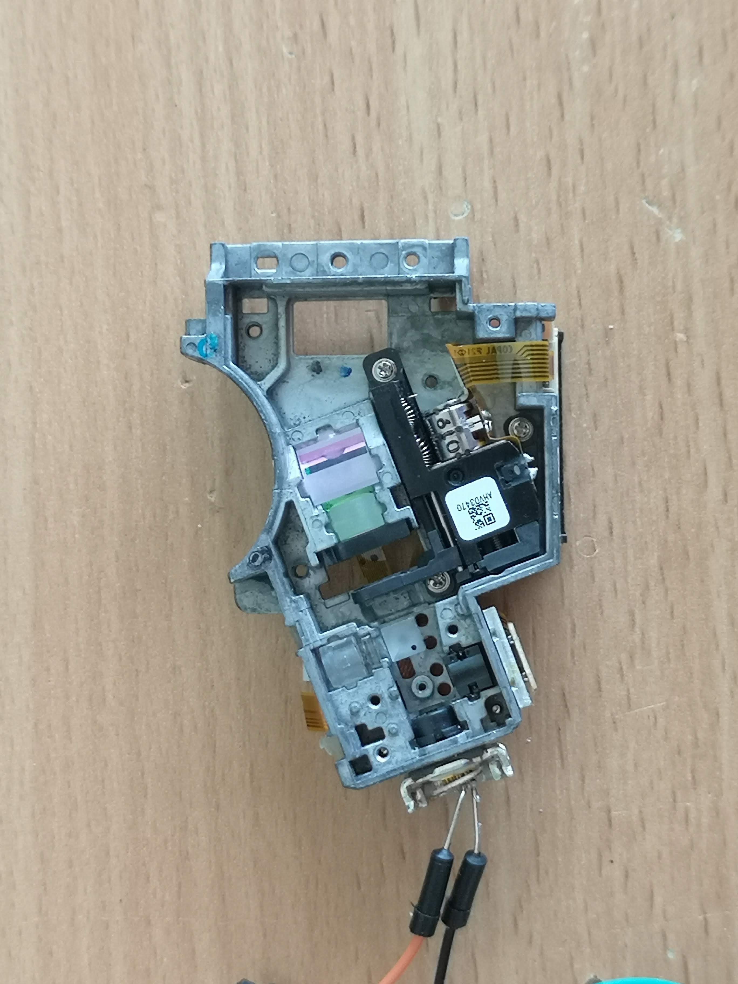
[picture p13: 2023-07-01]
IMAGES/AF_5.jpg

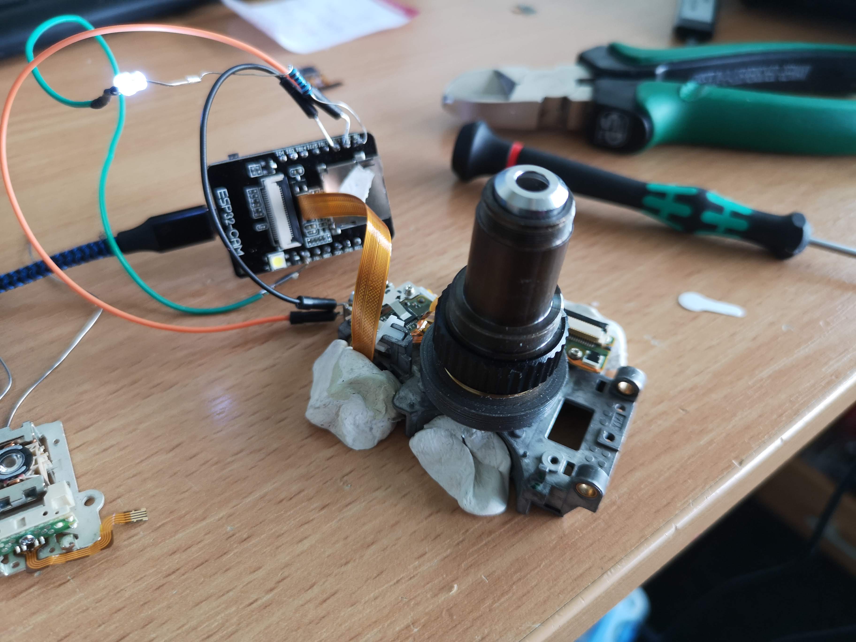
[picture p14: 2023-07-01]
IMAGES/AF_3.jpg

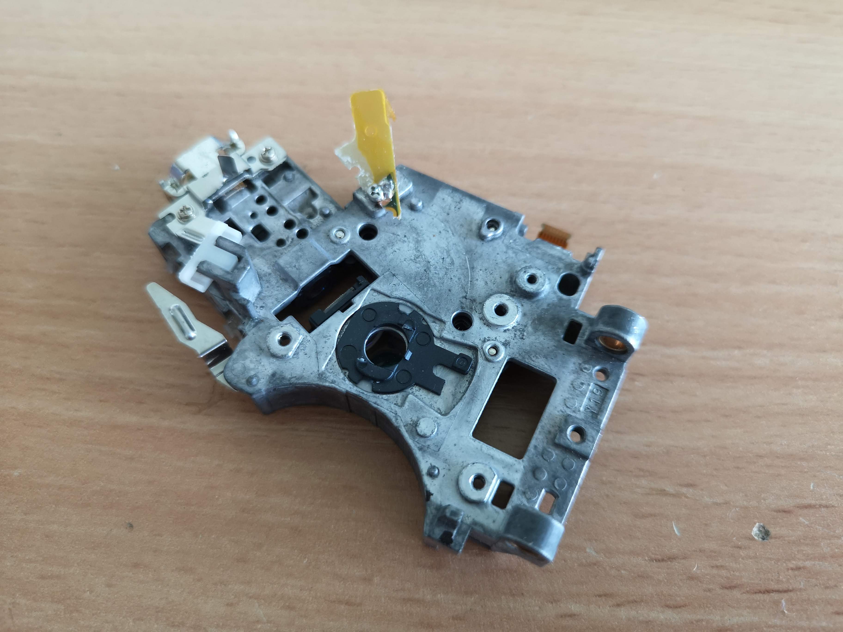
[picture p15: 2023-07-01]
IMAGES/AF_10.jpg

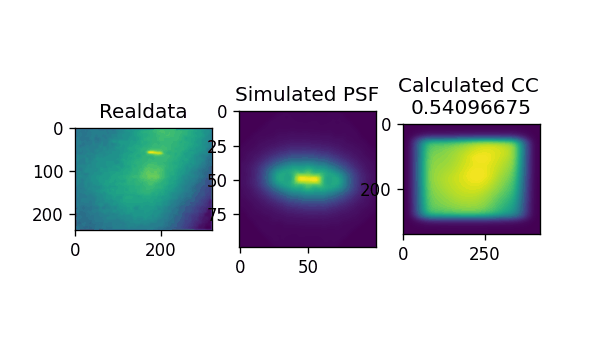
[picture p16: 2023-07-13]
IMAGES/psfCC.gif

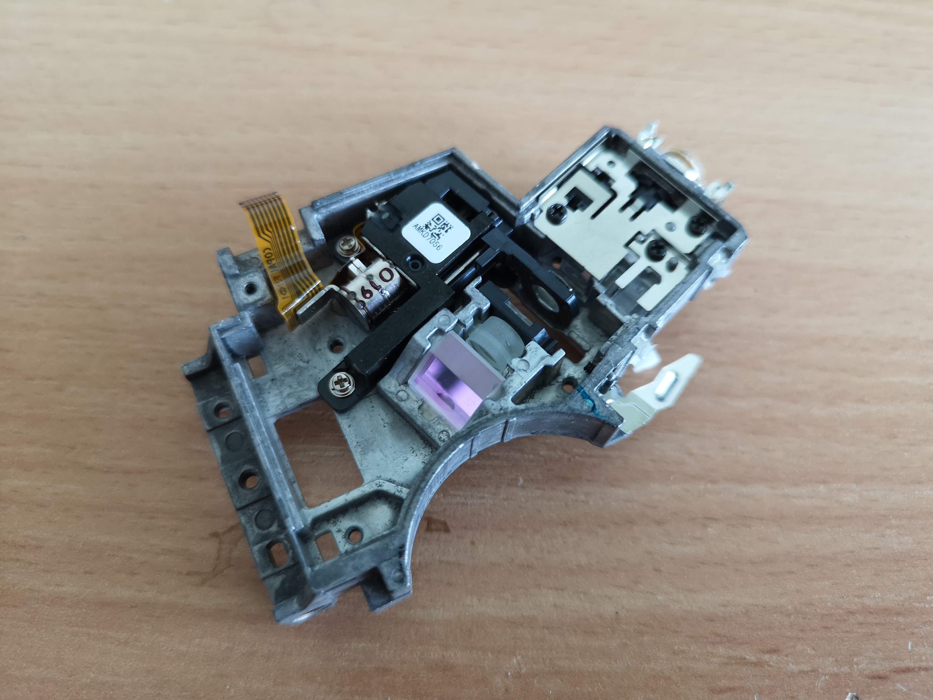
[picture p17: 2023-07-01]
IMAGES/AF_11.jpg

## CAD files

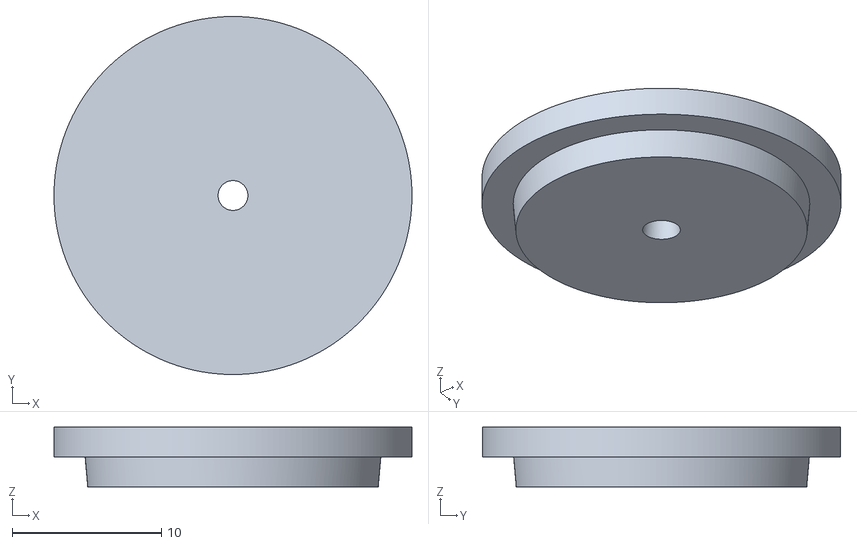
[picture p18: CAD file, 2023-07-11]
STL/STL_20_Cube_Insert_Autofocus_KES400a_mirrorinsert_alignmenttube_3.stl
24.0 x 24.0 x 4.00

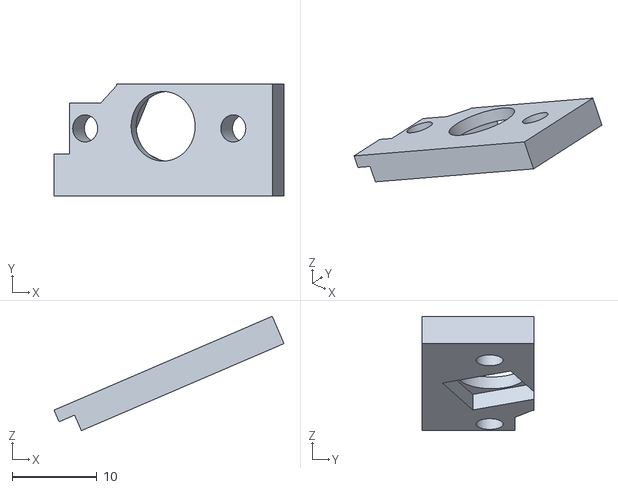
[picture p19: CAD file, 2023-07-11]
STL/STL_30_Linear_Stage_NEMA11_baseholder_bayonetmount_objective_autofocus_kes400_camerabracket_underAnAngle_6.stl
27.1 x 13.2 x 13.5

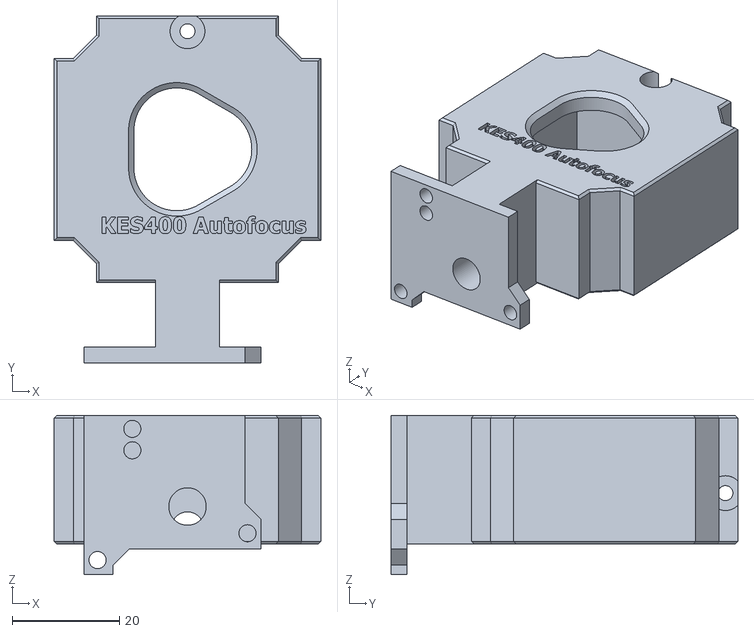
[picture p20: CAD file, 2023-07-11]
STL/STL_20_Cube_Insert_Autofocus_KES400a_mirrorinsert_1.stl
49.8 x 64.8 x 29.7

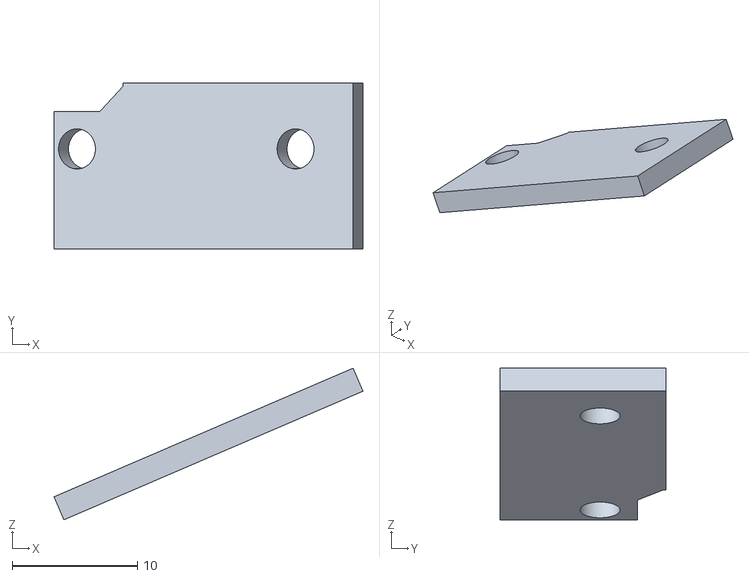
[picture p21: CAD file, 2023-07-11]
STL/STL_30_Linear_Stage_NEMA11_baseholder_bayonetmount_objective_autofocus_kes400_camerabracket_underAnAngle_counterplate_7.stl
24.7 x 13.2 x 12.1

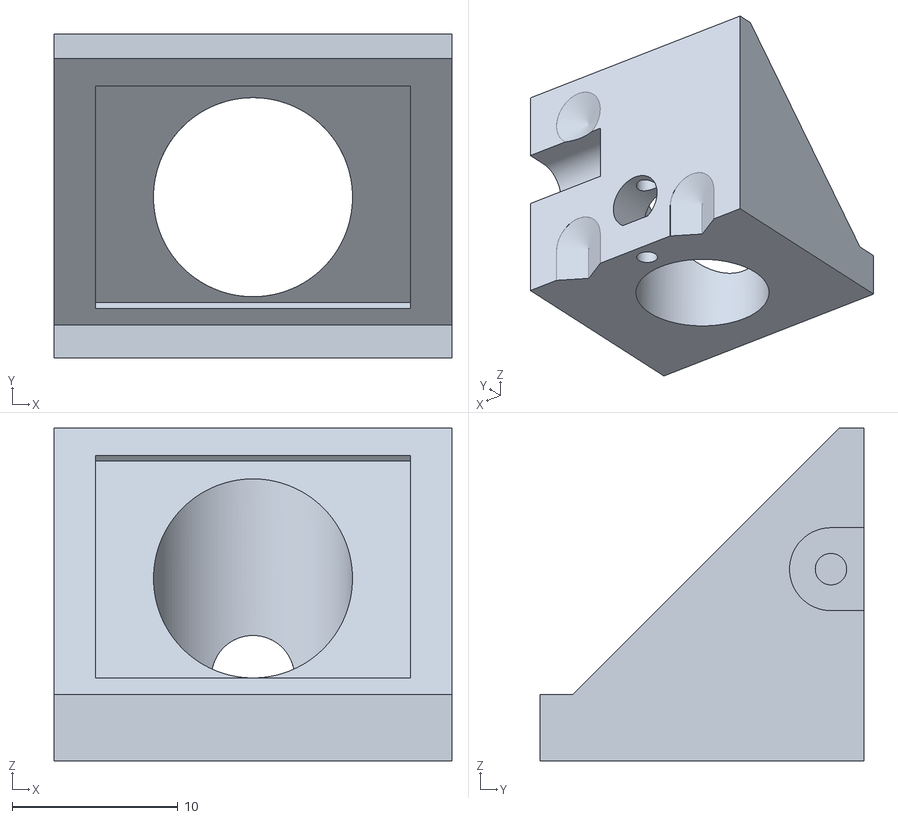
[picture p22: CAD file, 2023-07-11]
STL/STL_20_Cube_Insert_Autofocus_KES400a_mirrorinsert_mirrorholder_2.stl
24.0 x 19.6 x 20.1

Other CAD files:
INVENTOR/00_ESP32_XIAO_Adapter_SDcard.ipt
INVENTOR/00_ESP32_XIAO_Adapter_base.ipt
INVENTOR/00_ESP32_XIAO_Adapter_lid.ipt
INVENTOR/00_KES400.iam
INVENTOR/00_KES400A_base.ipt
INVENTOR/00_KES400_Bluray_Lens.ipt
INVENTOR/00_KES400_Lens.ipt
INVENTOR/00_KES_Bluray_Magnet.ipt
INVENTOR/00_M3_Ballheaded_screw_20mm.ipt
INVENTOR/00_Seeeduino Xiao.ipt
INVENTOR/00_Spring_3mm_3mm.ipt
INVENTOR/00_Xia_KES400_Lens_adapter.ipt
INVENTOR/20_Cube_Insert_Autofocus_KES400a_mirrorinsert.ipt
INVENTOR/20_Cube_Insert_Autofocus_KES400a_mirrorinsert_alignmenttube.ipt
INVENTOR/20_Cube_Insert_Autofocus_KES400a_mirrorinsert_mirrorholder.ipt
INVENTOR/30_Linear_Stage_NEMA11_baseholder_bayonetmount_objective_autofocus_kes400_camerabracket_underAnAngle.ipt
INVENTOR/30_Linear_Stage_NEMA11_baseholder_bayonetmount_objective_autofocus_kes400_camerabracket_underAnAngle_counterplate.ipt
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

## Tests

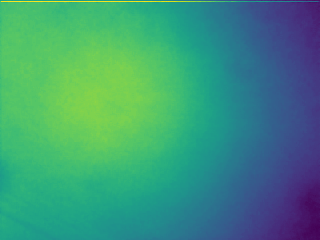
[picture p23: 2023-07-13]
blufocus/testbyte.png

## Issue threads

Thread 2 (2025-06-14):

Autofocus System Software Specification (Raspberry Pi Zero W2)

beniroquai, 2025-06-14:
An example code can be found in the folder /RASPI

## 1 Scope
Design and implement lightweight software that acquires camera frames, evaluates focus quality for each frame, streams video for debugging, exposes runtime configuration via REST, and publishes per‑frame focus metrics over CAN bus. Runs headless on Raspberry Pi Zero W2 and ships as a bootable OS image.

## 2 Target Hardware
| Component | Details |
|-----------|---------|
| SBC | Raspberry Pi Zero W2, 1 GHz quad‑core, 512 MB RAM |
| Camera | CSI‑2 camera (e.g. HQ camera); sensor supports manual exposure & gain |
| CAN | Waveshare RS485_CAN_HAT connected to Pi GPIO / SPI |
| Network | 2.4 GHz Wi‑Fi (credentials pre‑set via **boot.txt**) |

## 3 Operating System & Base Image
* Raspberry Pi OS Lite 64‑bit (Debian 12)
* Custom image built with `pi-gen`; Wi‑Fi SSID/PSK injected into `/boot/wpa_supplicant.conf`.
* Enable UART, I2C, SPI, and camera in `/boot/config.txt`.

## 4 Processes & Services
### 4.1 `focusd` – main service (Python ≥3.11)
* Captures frames from the CSI camera at ≤ 15 fps using `libcamera`.
* Applies user‑defined exposure & gain on each capture.
* Calls **FocusMetric.compute(frame)** (algorithm described in §5) and obtains a single `float` per frame.
* Publishes metric to CAN (event‑push every frame *and* on‑demand pull, §6).
* Exposes MJPEG stream of raw frames on `http://<pi>:8080/stream.mjpg` for live debug.
* Exposes REST API via FastAPI (see §7).
* Persists settings in `/etc/focusd/config.yaml`; loads on startup.
* Implemented as `systemd` service; auto‑restart.

### 4.2 `focusd_api` (FastAPI under Uvicorn)
Runs inside same process or separate; provides REST + WebSocket.

### 4.3 `can0` bring‑up script
```bash
ip link set can0 type can bitrate 100000
ifconfig can0 up
```
Add to `/etc/rc.local` or dedicated `systemd` service.

## 5 Focus Metric Algorithm
1. Convert frame to grayscale (`numpy uint8`).
2. (Optional) Gaussian blur σ ≈ 11 px to suppress noise.
3. Threshold: `im[im < background] = 0`, `background` configurable.
4. Compute mean projections `projX`, `projY`.
5. Fit `projX` with double‑Gaussian, `projY` with single‑Gaussian (SciPy `curve_fit`).
6. Focus value `F = σx / σy` (float32).
7. Return timestamped JSON `{ "t": 1686844861.012, "focus": F }`.

Provide `focus_algorithm.py` with clear API so algorithm can later be hot‑swapped or ported to C++.

## 6 CAN Bus Interface
* `socketcan` driver.
* Arbitration ID: `0x123` (configurable).
* Data payload: first 4 bytes little‑endian IEEE‑754 float = focus value; remaining bytes reserved.
* Push mode: transmit every processed frame.
* Pull mode: on receiving CAN message with ID `0x124`, immediately send latest value.
* Use `python‑can`; abstraction layer so C++ can reuse message format.

## 7 REST API (FastAPI)

This is mostly for debugging; useses Swagger

| Method & path | Purpose |
|---------------|---------|
| `GET /status` | health, version, uptime |
| `GET /config` | return current config YAML |
| `POST /config` | update config; body = partial YAML |
| `POST /capture` | grab single frame, return JPEG |
| `GET /focus` | latest focus value JSON |
| `GET /stream` | stream mjpeg data |

All writes trigger persistent save to `/etc/focusd/config.yaml`.

## 8 Performance Targets
* CPU ≤ 70 % of single core at 10 fps.
* RAM ≤ 120 MB resident.
* Boot‑to‑ready ≤ 25 s.
* CAN latency (frame → publish) ≤ 40 ms.

## 9 Logging & Monitoring
* `systemd‑journald` for service stdout/err.
* Optional MQTT publishing of metrics for remote dashboards.
* Rotate MJPEG stream to RAM‑disk to avoid SD wear.

## 10 Deployment & Deliverables
1. **Git repo** with structured modules:
   * `focusd/` core service
   * `api/` FastAPI app
   * `algorithms/` focus metrics
   * `scripts/` bring‑up, build‑image
2. **Dockerfile** for CI lint/unit‑tests (runs on x86 CI server).
3. **Pi image build script** (`build_image.sh`) producing `focusd-<date>.img`.
4. **README.md**: flashing instructions, API examples, CAN trace examples.
5. **Unit tests** (pytest) incl. synthetic frame fixtures.
6. **Benchmark report** against performance targets.
7. Optional: C++ port stub using `pybind11`.

## 11 Timeline (example)
| Week | Milestone |
|------|-----------|
| 1 | repo skeleton, CAN setup validated |
| 2 | camera capture + MJPEG + REST skeleton |
| 3 | algorithm integrated, unit tests passing |
| 4 | CAN push/pull implemented, performance tuned |
| 5 | image build pipeline, documentation, hand‑off |

## 12 Acceptance Criteria
* Flash image, power‑up Pi, connect to predefined Wi‑Fi, open `http://<pi>:8080/stream.mjpg` and see live video.
* `curl -X POST /config -d '{"exposure":1500}'` updates sensor and value persists after reboot.
* External CAN bus receives focus value for every frame within 40 ms.
* System meets performance & resource constraints.

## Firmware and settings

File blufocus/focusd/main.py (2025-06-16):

"""
Main focusd service

Integrates all components according to specification:
- Captures frames from CSI camera at ≤ 15 fps using libcamera
- Applies user-defined exposure & gain on each capture  
- Calls FocusMetric.compute(frame) and obtains single float per frame
- Publishes metric to CAN (event-push every frame and on-demand pull)
- Exposes MJPEG stream of raw frames over HTTPS on port 8080 to avoid mixed content issues
- Exposes REST API via FastAPI
- Persists settings in /etc/focusd/config.yaml; loads on startup
"""

import logging
import logging.handlers
import signal
import sys
import time
import threading
import asyncio
import atexit
from typing import Optional
import uvicorn

from focusd.config import ConfigManager
from focusd.camera import CameraInterface  
from focusd.can_interface import CANInterface, setup_can_interface
from focusd.mjpeg_streamer import MJPEGStreamer
from focusd.ssl_utils import ensure_certificates_exist, validate_certificates
from algorithms.focus_algorithm import FocusMetric, FocusConfig
from api.main import FocusdAPI


class FocusdService:
    """Main focusd service orchestrator"""
    
    def __init__(self, config_path: Optional[str] = None):
        self.config_manager = ConfigManager(config_path)
        self.config = self.config_manager.load_config()
        
        # Setup logging
        self._setup_logging()
        self.logger = logging.getLogger(__name__)
        
        # Initialize components
        self.camera: Optional[CameraInterface] = None
        self.can_interface: Optional[CANInterface] = None  
        self.mjpeg_streamer: Optional[MJPEGStreamer] = None
        self.focus_metric: Optional[FocusMetric] = None
        self.api: Optional[FocusdAPI] = None
        self.uvicorn_server: Optional[uvicorn.Server] = None
        
        self.is_running = False
        self._shutdown_event = threading.Event()
        self._shutdown_requested = False
        
        # Performance tracking
        self.frame_count = 0
        self.start_time = time.time()
        self.last_performance_log = time.time()
        
        # Register cleanup on exit
        atexit.register(self.stop)
        
    def _setup_logging(self):
        """Setup logging configuration"""
        log_level = getattr(logging, self.config.system.log_level.upper(), logging.INFO)
        
        logging.basicConfig(
            level=log_level,
            format='%(asctime)s - %(name)s - %(levelname)s - %(message)s',
            handlers=[
                logging.StreamHandler(sys.stdout),
                logging.handlers.SysLogHandler(address='/dev/log') if sys.platform.startswith('linux') else logging.StreamHandler()
            ]
        )
    
    def start(self) -> bool:
        """Start all focusd components"""
        try:
            self.logger.info("Starting focusd autofocus service...")
            
            # Setup CAN interface first
            if not self._setup_can():
                return False
            
            # Initialize focus algorithm
            self._setup_focus_algorithm()
            
            # Initialize camera
            if not self._setup_camera():
                return False
            
            # Initialize MJPEG streamer
            if not self._setup_mjpeg_streamer():
                return False
            
            # Initialize API
            if not self._setup_api():
                return False
            
            self.is_running = True
            
            # Setup signal handlers
            signal.signal(signal.SIGTERM, self._signal_handler)
            signal.signal(signal.SIGINT, self._signal_handler)
            
            self.logger.info("focusd service started successfully")
            return True
            
        except Exception as e:
            self.logger.error(f"Failed to start focusd service: {e}")
            self.stop()
            return False
    
    def _setup_can(self) -> bool:
        """Setup CAN interface"""
        try:
            # Setup CAN interface at system level
            if not setup_can_interface(self.config.can.interface, self.config.can.bitrate):
                self.logger.warning("Failed to setup CAN interface, continuing without CAN")
                return True  # Don't fail startup due to CAN issues
            
            # Initialize CAN interface
            self.can_interface = CANInterface(
                interface=self.config.can.interface,
                bitrate=self.config.can.bitrate,
                tx_id=self.config.can.arbitration_id_tx,
                rx_id=self.config.can.arbitration_id_rx
            )
            
            if self.can_interface.start():
                self.can_interface.set_push_mode(self.config.can.enable_push_mode)
                self.can_interface.set_pull_mode(self.config.can.enable_pull_mode)
                self.logger.info("CAN interface initialized")
            else:
                self.logger.warning("CAN interface failed to start, continuing without CAN")
                self.can_interface = None
                
            return True
            
        except Exception as e:
            self.logger.warning(f"CAN setup failed: {e}, continuing without CAN")
            self.can_interface = None
            return True
    
    def _setup_focus_algorithm(self):
        """Setup focus algorithm"""
        focus_config = FocusConfig(
            gaussian_sigma=self.config.focus_algorithm.gaussian_sigma,
            background_threshold=self.config.focus_algorithm.background_threshold,
            crop_radius=self.config.focus_algorithm.crop_radius,
            enable_gaussian_blur=self.config.focus_algorithm.enable_gaussian_blur
        )
        
        self.focus_metric = FocusMetric(focus_config)
        self.logger.info("Focus algorithm initialized")
    
    def _setup_camera(self) -> bool:
        """Setup camera interface"""
        try:
            self.camera = CameraInterface(
                width=self.config.camera.width,
                height=self.config.camera.height,
                fps=self.config.camera.fps
            )
            
            self.camera.update_settings(
                exposure=self.config.camera.exposure,
                gain=self.config.camera.gain
            )
            
            # Set frame callback for processing
            self.camera.set_frame_callback(self._process_frame)
            
            if self.camera.start():
                self.logger.info("Camera interface initialized")
                return True
            else:
                self.logger.error("Failed to start camera")
                return False
                
        except Exception as e:
            self.logger.error(f"Camera setup failed: {e}")
            return False
    
    def _setup_mjpeg_streamer(self) -> bool:
        """Setup MJPEG streamer"""
        try:
            self.mjpeg_streamer = MJPEGStreamer(quality=85)
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

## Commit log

2023-07-11 Adding Inventor Designfiles
    [00_ESP32_XIAO_Adapter_SDcard.ipt, 00_ESP32_XIAO_Adapter_base.ipt, 00_ESP32_XIAO_Adapter_lid.ipt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]
2023-07-11 Adding Images and STL files
    [STL_00_KES400A_base_4.stl, STL_00_M3_Ballheaded_screw_20mm_10.stl, STL_00_M3_Ballheaded_screw_20mm_8.stl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]
2025-06-16 Enable HTTPS by default for MJPEG streaming to fix mixed content issues
    [config.py, main.py, mjpeg_streamer.py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]
